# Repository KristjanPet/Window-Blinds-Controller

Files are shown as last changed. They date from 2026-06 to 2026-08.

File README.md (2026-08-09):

> [!NOTE]
> This is the first hardware version of the project. Both the PCB and mechanical design are relatively bulky; a second revision is in development with the goal of reducing the overall size by approximately 80%.
>
> Contributions, design ideas, and improvement suggestions are more than welcome.

# Window Blinds Controller

ESP32-S3 based embedded controller for motorized window blinds, built with C++/ESP-IDF, TMC2209 stepper control, FreeRTOS event-driven architecture, MQTT integration, custom KiCad PCB, and custom mechanical parts.

<p align="center">
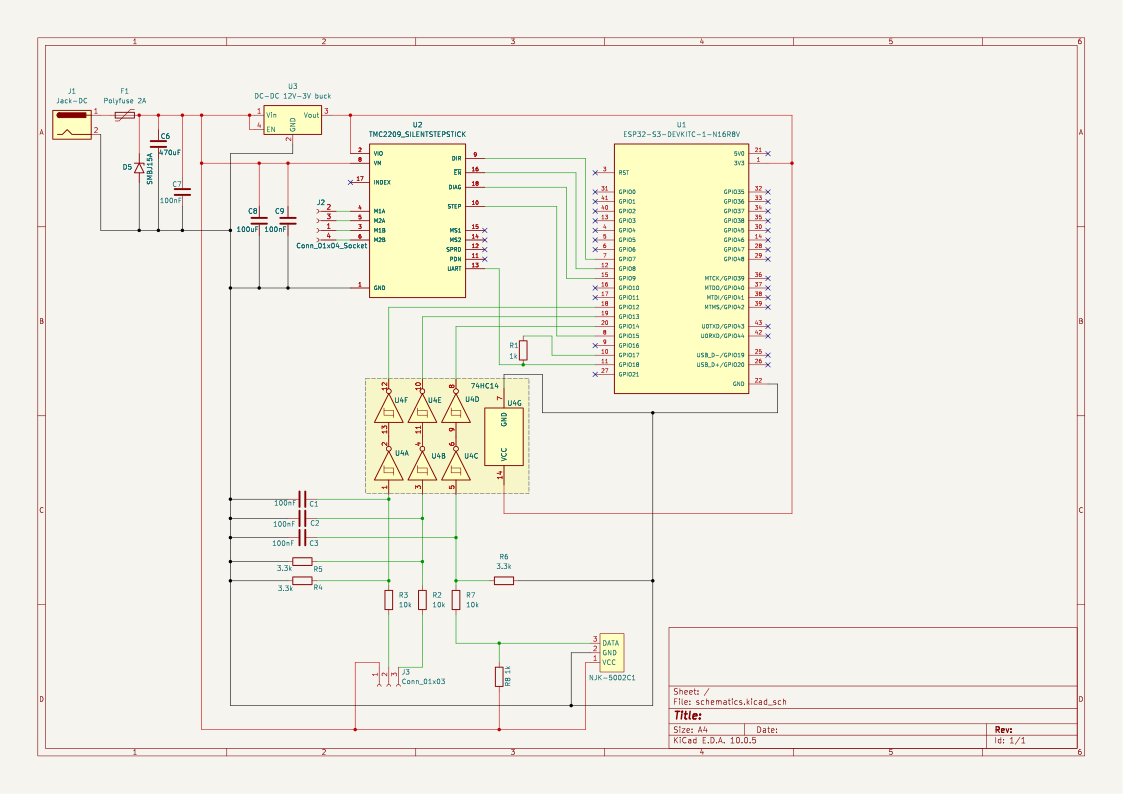
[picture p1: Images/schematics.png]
  
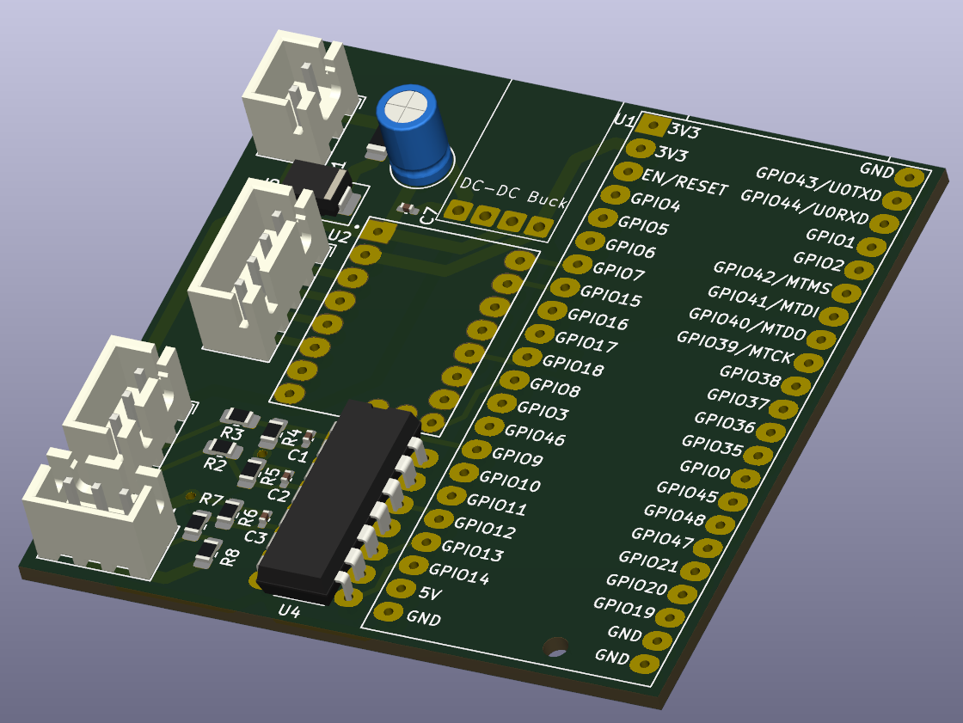
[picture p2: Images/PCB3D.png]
  
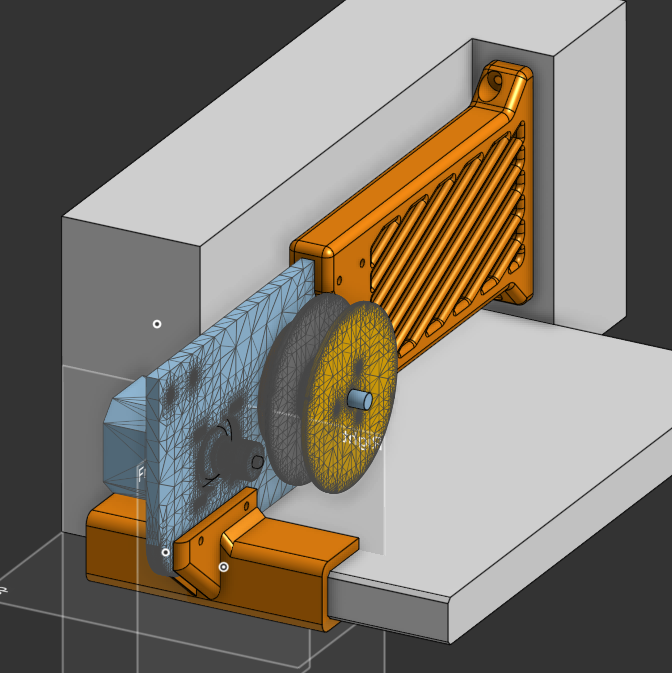
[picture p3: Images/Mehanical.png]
  
</p>
<p align="center">
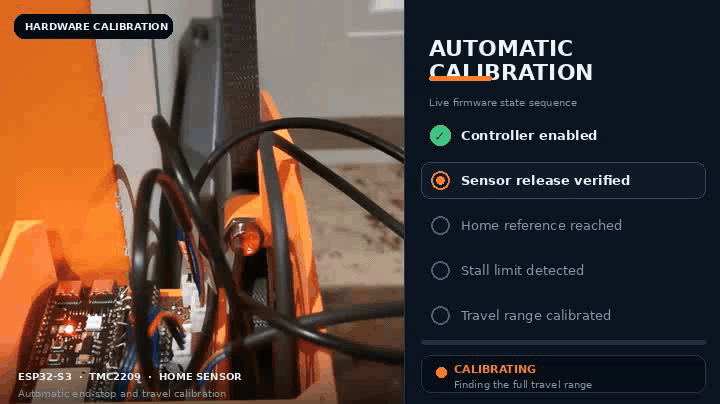
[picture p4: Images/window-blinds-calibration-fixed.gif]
ESP32-S3 window blinds automatic calibration with sensor verification, homing and stall detection
  
</p>

## What this project demonstrates

- Embedded C++ architecture using separated modules and interfaces
- ESP32-S3 firmware development with ESP-IDF and PlatformIO
- FreeRTOS task-based design with a central command/event queue
- Stepper motor control using RMT pulse generation and PCNT position tracking
- TMC2209 UART driver configuration and DIAG/stall event handling
- Homing, calibration, soft limits, stall recovery, and fault-state handling
- MQTT-based smart-home command interface
- Unit testing with PlatformIO/Unity and fake hardware abstractions
- Custom KiCad schematic and PCB design
- Custom mechanical design: CNC aluminium motor/rope holder and 3D printed enclosure
- Doxygen API documentation
- Project planning using Jira and draw.io diagrams

---

## Hardware

Main components:

| Component | Purpose |
|---|---|
| ESP32-S3 | Main MCU, Wi-Fi, FreeRTOS firmware |
| TMC2209 | Stepper motor driver with UART configuration and DIAG/stall signal |
| Nema 17 Stepper motor | Blind movement |
| NJK-5002C Home/reference sensor | Calibration and homing |
| Wall buttons | Local manual control |
| Custom PCB | Power, MCU, driver, sensor, and connector integration |

## Mechanical design

The project also includes custom mechanical parts:

- CNC aluminium motor and rope holder for the blind mechanism
- 3D printed front/back mounting holders for aluminium
- 3D printed electronics case
- 3D printed cover
- CAD models and exported STL/STEP files

## Documentation and planning

- Doxygen configuration for generated C++ API documentation
- draw.io diagrams for system architecture and firmware flow
- Jira used for task planning, issue tracking, and development organization

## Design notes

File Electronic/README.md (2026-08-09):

# Electronics Hardware

This folder contains the PCB and electronics design files for the window blinds controller.

The electronics are built around an ESP32-S3 development board, a TMC2209 stepper motor driver, a 12 V to 5 V buck converter, input protection, button/sensor connectors, and dual-inverter Schmitt-trigger input paths.

## Schematics



## Main electronics

| Component | Qty | Value / Part | Purpose |
| --- | --: | --- | --- |
| ESP32-S3 development board | 1 | `ESP32-S3-DEVKITC-1-N16R8V` | Main MCU, firmware, Wi-Fi, MQTT, GPIO control |
| Stepper driver | 1 | `TMC2209 SilentStepStick` | Stepper motor driver with UART configuration and DIAG/StallGuard output |
| Buck converter | 1 | 12 V to 3 V DC-DC buck | Generates 3 V supply from the 12 V input |
| Schmitt trigger | 1 | `74HC14` | Cleans three input signals with two inverter gates per signal |
| TVS diode | 1 | `SMBJ15A` | 12 V input transient protection |
| Polyfuse | 1 | 2 A | Input overcurrent protection |

## Passive components

| Component type | Qty | Value  |
| --- | --: | --- |
| Capacitors | 4 | 100 nF |
| Capacitor | 1 | 470 µF |
| Resistors | 2 | 1 kΩ |
| Resistors | 3 | 10 kΩ  |
| Resistors | 3 | 3.3 kΩ |

## Connectors

| Connector | Qty | Purpose |
| --- | --: | --- |
| 2-pin JST-XH | 1 | Power input |
| 4-pin JST-XH | 1 | External wiring / motor-driver related connection |
| 3-pin JST-XH | 1 | External input buttons connection |
| 3-pin JST-XH | 1 | NJK-5002C home sensor connection |

## Conditioned input logic

Each external input passes through two gates of the 74HC14. The two inversions
cancel, so the ESP32-S3 sees the same logical polarity as the signal entering the
first gate. The final gate is a 3.3 V push-pull output, so the firmware keeps the
ESP32 internal pull resistors disabled.

| Input | ESP32-S3 pin | Pre-Schmitt idle | Pre-Schmitt active | ESP32 idle | ESP32 active | Activation edge |
| --- | ---: | ---: | ---: | ---: | ---: | ---: |
| Up button | `GPIO12` | LOW | HIGH | LOW | HIGH | Rising |
| Down button | `GPIO13` | LOW | HIGH | LOW | HIGH | Rising |
| Home sensor | `GPIO14` | HIGH | LOW | HIGH | LOW | Falling |

## External hardware

The PCB is designed to work with the following external hardware:

| Part | Notes |
| --- | --- |
| 12 V, 3 A power supply adapter | Main power input for the controller and motor system |
| NEMA 17 stepper motor `17HS4401` | Stepper motor used to drive the blinds mechanism |
| GREATZT NJK-5002C Hall effect proximity sensor | Home/reference sensor for calibration |

Before choosing the motor and power supply, the weight and friction of the specific blinds should be checked. Heavier blinds, tight mechanisms, or higher-friction rope systems may require more torque, different gearing, or a stronger motor/driver setup.

## Design notes

The current PCB uses development-board style modules for the ESP32-S3, TMC2209 SilentStepStick, and DC-DC buck converter.

This made the prototype easier to build and debug because those modules were available during development. If space is critical, these modules could be replaced with direct SMD implementations in a future PCB revision.

Possible future optimizations:

* replace ESP32-S3 DevKit with the ESP32-S3 module (or any other not so overpowerd ESP) directly on the PCB
* replace TMC2209 SilentStepStick with the bare TMC2209 IC and required support components
* replace the buck converter module with an onboard SMD regulator circuit
* reduce connector size or move connectors based on the final enclosure
* optimize PCB shape for the mechanical case

<p align="center">
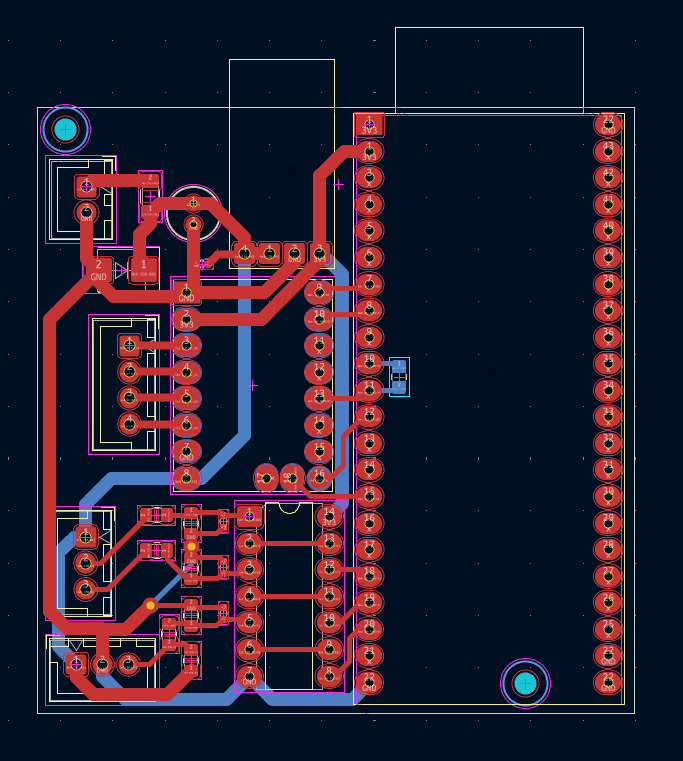
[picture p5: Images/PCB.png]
  
  
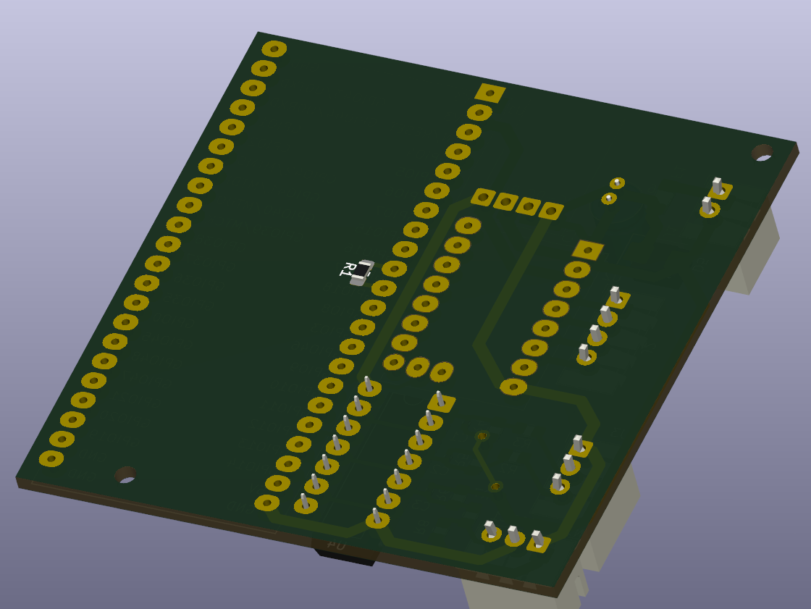
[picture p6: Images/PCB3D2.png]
  
</p>

## Safety note

This board controls a motorized mechanism. Before installation, verify:

* correct supply voltage and polarity
* current rating of the power adapter
* stepper motor current settings
* fuse/protection behavior
* connector wiring
* home sensor behavior
* motor direction
* stall detection
* mechanical end stops

Do not operate the blinds unattended until calibration, stall detection, and fault handling have been tested on the real mechanism.

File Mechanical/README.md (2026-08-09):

# Mechanical Hardware

This folder contains the mechanical design files for the window blinds controller.

The design includes CNC-machined aluminium parts, 3D printed holders, and a 3D printed electronics enclosure.

<p align="center">
  
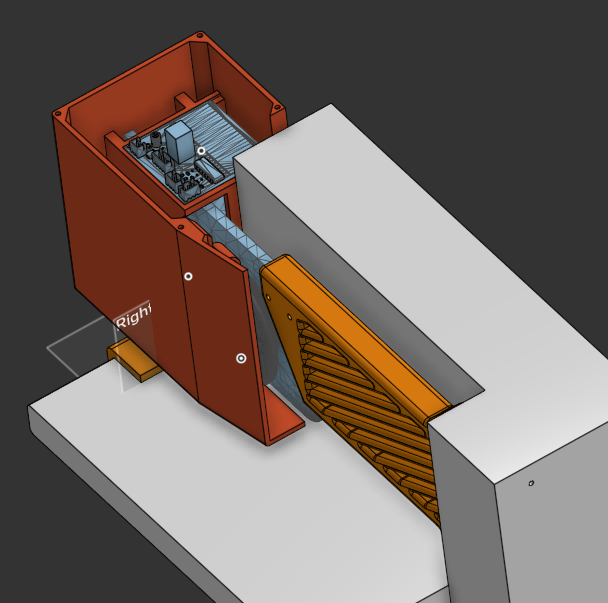
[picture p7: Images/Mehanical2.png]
  
</p>

## Main parts

| Part | Manufacturing method | Purpose |
| --- | --- | --- |
| Motor/rope holder | CNC aluminium | Holds the stepper motor and rope drive mechanism |
| Front holder | 3D printed or CAD reference | Supports the aluminium holder assembly |
| Back holder | 3D printed or CAD reference | Supports the aluminium holder assembly |
| Electronics case  | 3D printed | Holds the PCB, homing sensor, wiring, and sound absorbing foam |
| Cover | 3D printed | Removable cover for access and future upgrades |
| 1:8 pitch timing belt | bought online	  | increases available torque at the rope mechanism |

## Design notes

The aluminium motor/rope holder was CNC machined. The initial plan was to use only this aluminium part and mount it directly to the wall. Due to limited available space around the window and blinds, additional front/back holder parts were added around it.

The aluminium holder could also be 3D printed, or redesigned as a combined part together with the front and/or back holder, depending on the mounting constraints.

The overall mechanical design is probably overengineered and could be optimized. The best final shape depends strongly on the specific window frame, blind type, available mounting space, and required torque.

## Drive mechanism

A 1:8 pitch timing belt reduction is used between the stepper motor and the rope drive.

This increases available torque at the rope mechanism and gives the motor more control over blind movement.

## Fasteners

The assembly uses a few M4 bolts and screws. Exact lengths depend on the final printed/CNC part thickness and mounting surface.

## Electronics case

The electronics case is intentionally slightly larger than the minimum PCB size.

It includes space for:

* the main PCB
* homing sensor mounting
* PCB holders
* wiring clearance
* sound absorbing foam

The extra space was added to reduce noise and make the internal layout easier to service or modify.

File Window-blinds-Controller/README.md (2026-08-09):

# Firmware Project Structure

This folder contains the ESP32-S3 PlatformIO firmware project for the window blinds controller.

## Firmware architecture

The firmware is split into small C++ modules with clear responsibilities:

| Module | Responsibility |
|---|---|
| `BlindsController` | High-level state machine, calibration, movement policy, stall recovery |
| `MotorController` | STEP/DIR/EN control, RMT pulse generation, PCNT position tracking |
| `Tmc2209Driver` | UART register access, driver configuration, DIAG/stall event forwarding |
| `BlindsCommandQueue` | Central FreeRTOS command/event queue |
| `ButtonHandler` | Local wall-button input |
| `HomeSensor` | Reference sensor and homing validation |
| `MqttClient` | Remote commands and fault status publishing |
| `FaultHandler` | Thread-safe first-fault recording |

## Key engineering decisions

### RMT for step pulse generation
Stepper pulses are generated using the ESP32 RMT peripheral instead of software delay loops, reducing timing jitter and CPU load.

### PCNT for position tracking
The ESP32 PCNT peripheral is used to track generated step pulses and maintain position information.

### Event-driven control
Buttons, MQTT commands, motor events, home sensor events, and stall events are normalized into a central FreeRTOS command queue.

### Fault-first design
The system records the first fault and enters a safe fault state instead of silently ignoring failed operations.

### Testable architecture
High-level logic depends on interfaces/fakes where possible, allowing controller behavior and fault paths to be tested without real hardware.

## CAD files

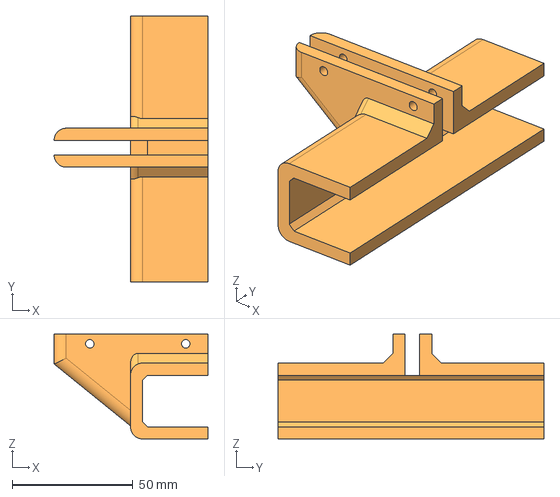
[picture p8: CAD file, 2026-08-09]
Mechanical/Back_Holder.step
63.6 x 110.0 x 43.4 mm

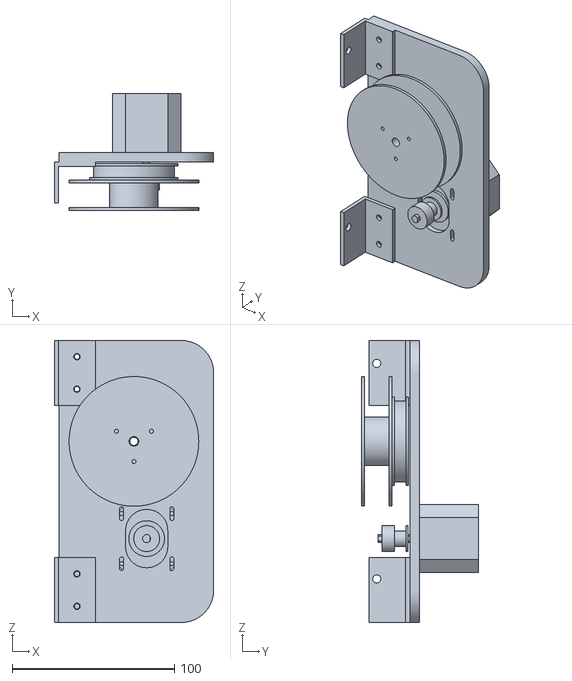
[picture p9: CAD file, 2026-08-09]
Mechanical/Aluminum_mechanism.stl
98.3 x 72.4 x 174.0

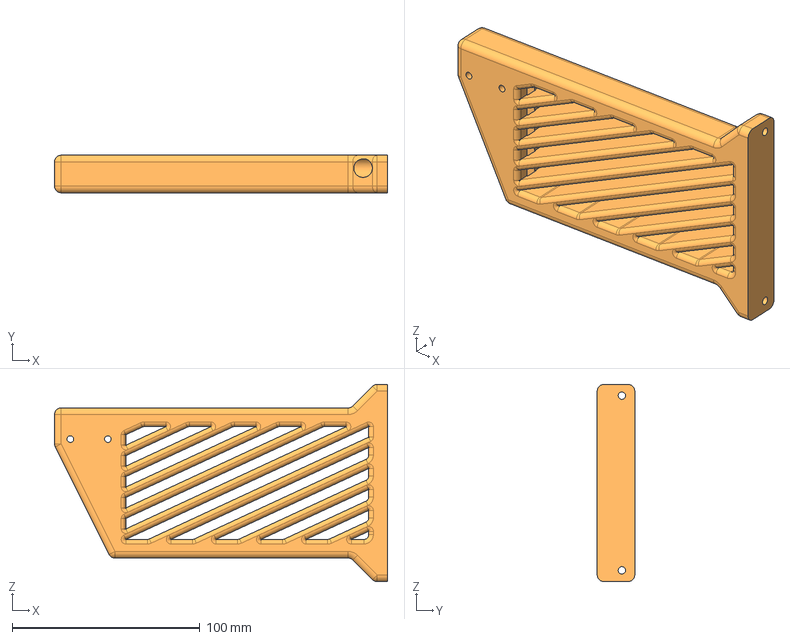
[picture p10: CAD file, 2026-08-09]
Mechanical/Front_Holder.step
177.3 x 20.0 x 105.0 mm

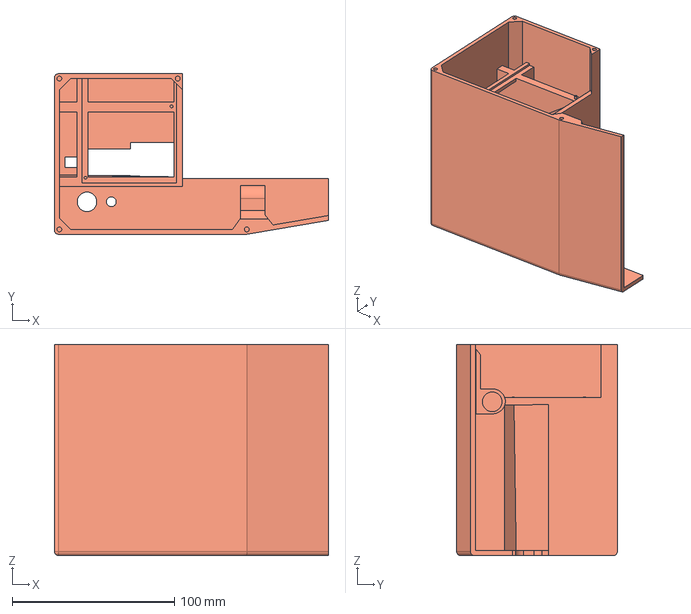
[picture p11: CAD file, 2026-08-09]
Mechanical/Case.step
168.6 x 98.8 x 130.0 mm

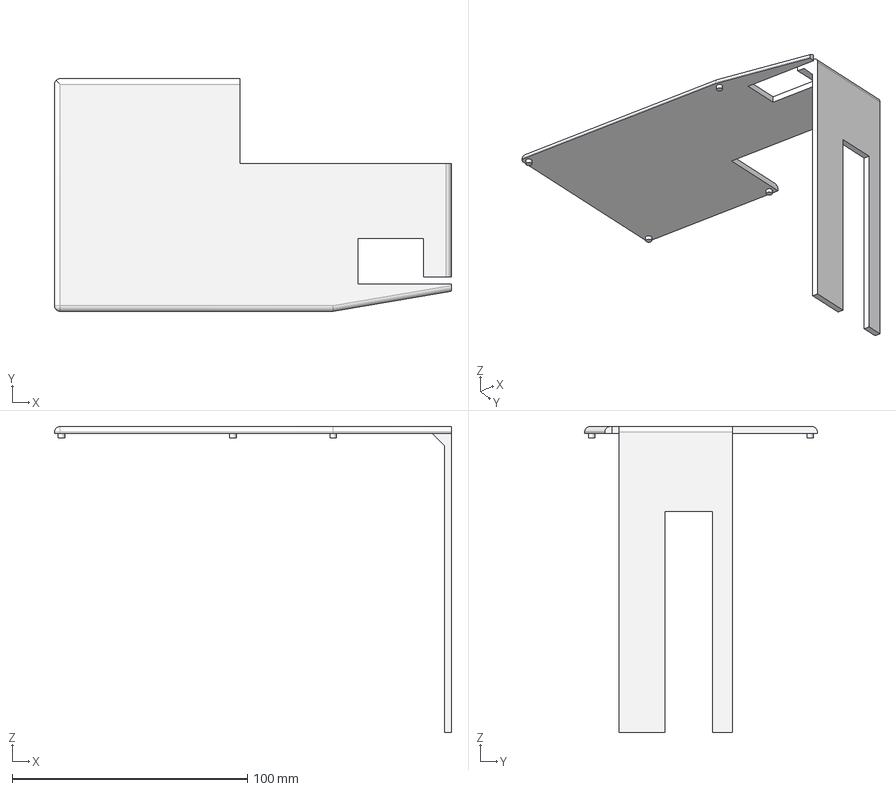
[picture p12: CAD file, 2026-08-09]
Mechanical/Cap.step
168.6 x 98.8 x 130.0 mm

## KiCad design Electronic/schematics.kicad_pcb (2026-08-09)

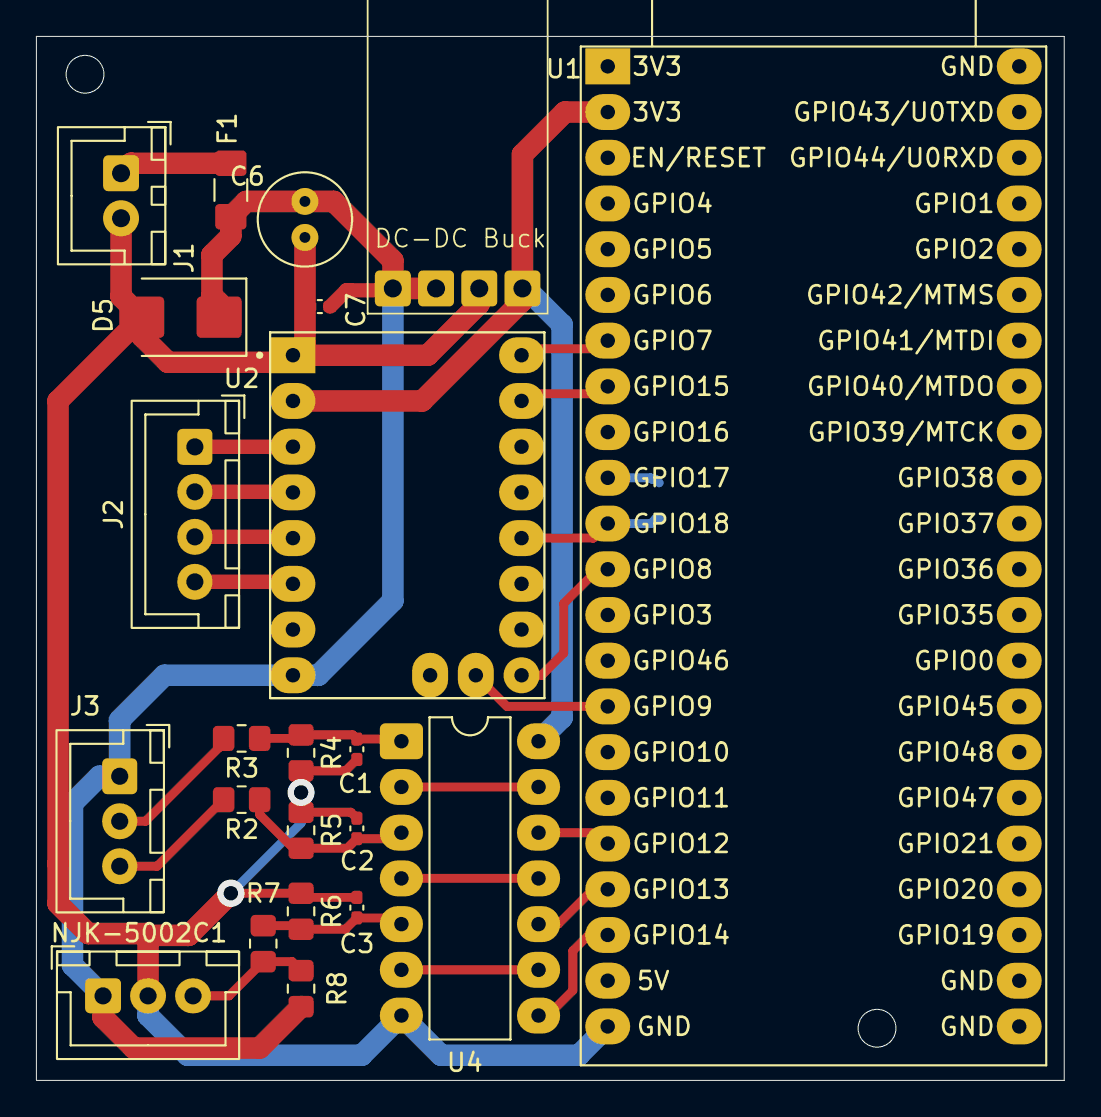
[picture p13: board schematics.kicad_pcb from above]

Board: 2 copper layers, 57.1 x 58.0 mm, 23 parts (1 on the bottom side), 26 nets.

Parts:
C1, C2, C3, C7: 100nF; C_0402_1005Metric_Pad0.74x0.62mm_HandSolder
C6: 470uF; C_Radial_D5.0mm_H7.0mm_P2.00mm
D5: SMBJ15A; D_SMB
F1: Polyfuse 2A; Fuse_1206_3216Metric_Pad1.42x1.75mm_HandSolder
J1: Jack-DC; JST_XH_B2B-XH-A_1x02_P2.50mm_Vertical
J2: Conn_01x04_Socket; JST_XH_B4B-XH-A_1x04_P2.50mm_Vertical
J3: Conn_01x03; JST_XH_B3B-XH-A_1x03_P2.50mm_Vertical
NJK-5002C1: JST_XH_B3B-XH-A_1x03_P2.50mm_Vertical
R1, R8: 1k; R_0805_2012Metric_Pad1.20x1.40mm_HandSolder
R2, R3, R7: 10k; R_0805_2012Metric_Pad1.20x1.40mm_HandSolder
R4, R5, R6: 3.3k; R_0805_2012Metric_Pad1.20x1.40mm_HandSolder
U1: ESP32-S3-DEVKITC-1-N16R8V; ESP32-S3-DevKitC
U2: TMC2209_SILENTSTEPSTICK; MODULE_TMC2209_SILENTSTEPSTICK
U3: DC-DC 12V-3V buck; DC-DC-Buck-converter-12V-5V
U4: 74HC14; DIP-14_W7.62mm_LongPads

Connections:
3V3: U1.1 (3V3), U2.2 (VIO), U3.3 (Vout), U4.14 (VCC)
GND: C1.1, C2.1, C3.1, C6.2, C7.2, D5.2 (A2), J1.2, NJK-5002C1.2 (GND), R4.2, R5.2, R6.2, U1.22 (GND), U2.1 (GND), U2.7 (GND), U3.2 (GND), U4.7 (GND)
unnamed: C1.2, R3.1, R4.1, U4.1
unnamed: C2.2, R2.1, R5.1, U4.3
unnamed: C3.2, R6.1, R7.2, U4.5
unnamed: J3.3, R2.2
unnamed: J3.2, R3.2
unnamed: NJK-5002C1.3 (DATA), R7.1, R8.2
unnamed: C6.1, C7.1, D5.1 (A1), F1.1, J3.1, NJK-5002C1.1 (VCC), R8.1, U2.8 (VM), U3.1 (Vin), U3.4 (EN)
unnamed: F1.2, J1.1
unnamed: J2.2 (Pin_1), U2.4 (M1A)
unnamed: J2.3 (Pin_2), U2.5 (M2A)
unnamed: J2.1 (Pin_3), U2.3 (M1B)
unnamed: J2.4, U2.6 (M2B)
unnamed: U1.7 (GPIO7), U2.9 (DIR)
unnamed: U1.12 (GPIO8), U2.16 (~EN)
unnamed: U1.15 (GPIO9), U2.18 (DIAG)
unnamed: U1.18 (GPIO12), U4.12
unnamed: U1.19 (GPIO13), U4.10
unnamed: U1.20 (GPIO14), U4.8
unnamed: U1.8 (GPIO15), U2.10 (STEP)
unnamed: R1.1, U1.10 (GPIO17)
unnamed: R1.2, U1.11 (GPIO18), U2.13 (UART)
unnamed: U4.6, U4.9
unnamed: U4.4, U4.11
unnamed: U4.2, U4.13

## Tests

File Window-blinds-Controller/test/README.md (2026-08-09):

## Testing

The firmware includes PlatformIO/Unity unit tests for:

- blinds state machine behavior
- button command handling
- stop and limit handling
- stall recovery logic
- calibration failure paths
- percentage-position movement
- MQTT command parsing
- JSON fault-status payload generation
- command queue and fault handling

Run tests:

```bash
pio test -e esp32-s3

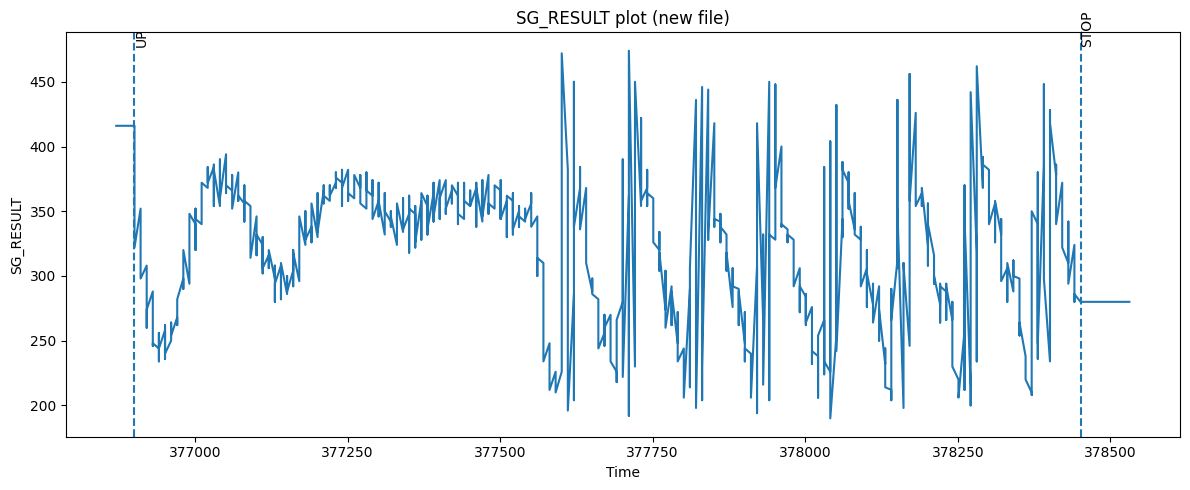
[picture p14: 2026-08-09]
Images/sg_result_close.png

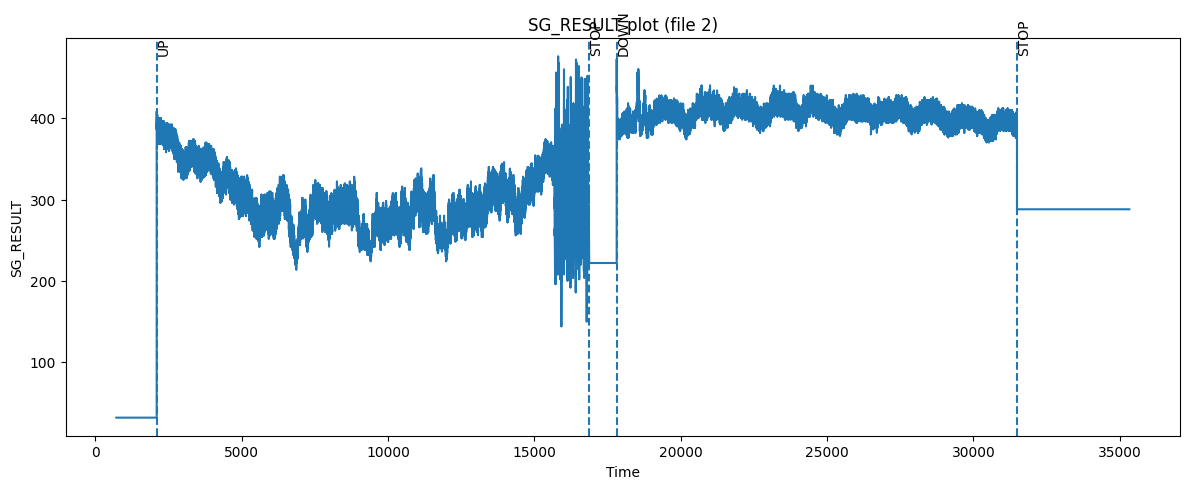
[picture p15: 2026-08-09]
Images/sg_result_all.png

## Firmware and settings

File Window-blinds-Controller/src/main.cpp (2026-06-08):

#include <esp_log.h>
#include <esp_system.h>
#include <driver/gpio.h>
#include <freertos/FreeRTOS.h>
#include <freertos/task.h>
#include "MotorController.hpp"
#include "ButtonHandler.hpp"
#include "HomeSensor.hpp"
#include "BlindsController.hpp"
#include "BlindsCommandQueue.hpp"
#include "Tmc2209Driver.hpp"
#include "AppConfig.hpp"
#include "FaultHandler.hpp"
#include "Wifi.hpp"
#include "MqttClient.hpp"
#include "ConnSecrets.hpp"

static const char *TAG_MAIN = "MAIN";

static FaultHandler faultHandler;
static BlindsCommandQueue commandsQueue(faultHandler);
static Tmc2209Driver motorDriver(AppConfig::UARTDriverPin, commandsQueue);
static MotorController motor(AppConfig::motorPins, commandsQueue, faultHandler);
static BlindsController blinds(motor, commandsQueue, faultHandler);
static ButtonHandler buttonHandler(AppConfig::buttonPins, commandsQueue);
static HomeSensor homeSensor(AppConfig::homeSensorPin, commandsQueue, faultHandler);
static Wifi wifi;
static MqttClient mqtt(commandsQueue, faultHandler);

extern "C" void app_main(void) {

    esp_err_t err = ESP_OK;
    err = commandsQueue.init();
    if(err != ESP_OK){
        ESP_LOGE(TAG_MAIN, "Command queue init failed: %s", esp_err_to_name(err));
        esp_restart();
    };

    err = gpio_install_isr_service(0);
    if(err != ESP_OK){
        ESP_LOGE(TAG_MAIN, "Failed to install GPIO ISR service: %s", esp_err_to_name(err));
        esp_restart();
    };

    err = motorDriver.init();
    if(err != ESP_OK){
        ESP_LOGE(TAG_MAIN, "TMC2209 init failed: %s", esp_err_to_name(err));
        esp_restart();
    };
    err = motorDriver.configureAndVerify();
    if(err != ESP_OK){
        ESP_LOGE(TAG_MAIN, "TMC2209 config failed: %s", esp_err_to_name(err));
        esp_restart();
    };

    err = motor.init();
    if(err != ESP_OK){
        ESP_LOGE(TAG_MAIN, "Motor init failed: %s", esp_err_to_name(err));
        esp_restart();
    };

    err = buttonHandler.init();
    if(err != ESP_OK){
        ESP_LOGE(TAG_MAIN, "Button handler init failed: %s", esp_err_to_name(err));
        esp_restart();
    };

    err = homeSensor.init();
    if(err != ESP_OK){
        ESP_LOGE(TAG_MAIN, "Home sensor init failed: %s", esp_err_to_name(err));
        esp_restart();
    };

    err = wifi.startAndConnect(ConnSecrets::wifiSsid, ConnSecrets::wifiPassword);
    if(err != ESP_OK){
        ESP_LOGW(TAG_MAIN, "WiFi start/connect failed, continuing without WiFi: %s", esp_err_to_name(err));
    }

    err = mqtt.init(ConnSecrets::mqttBrokerUri, ConnSecrets::mqttUsername, ConnSecrets::mqttPassword);
    if(err != ESP_OK){
        ESP_LOGW(TAG_MAIN, "MQTT init failed, continuing without MQTT: %s", esp_err_to_name(err));
    }
    else{
        err = mqtt.start(wifi.connectionEvents());
        if(err != ESP_OK){
            ESP_LOGW(TAG_MAIN, "MQTT start failed, continuing without MQTT: %s", esp_err_to_name(err));
        }
    }

    if(xTaskCreate(ButtonHandler::buttonTask, "Button", 2048, &buttonHandler, 3, NULL) != pdPASS){
        ESP_LOGE(TAG_MAIN, "Failed to create Button task, restarting...");
        esp_restart();
    }
    if(xTaskCreate(BlindsController::handleCommandTask, "Blinds", 4096, &blinds, 4, NULL) != pdPASS){
        ESP_LOGE(TAG_MAIN, "Failed to create handle command task, restarting...");
        esp_restart();
    }

    vTaskDelay(pdMS_TO_TICKS(500));
    ESP_LOGI(TAG_MAIN, "Init complete, checking sensor....");

    err = homeSensor.sensorCheck();
    if(err != ESP_OK){
        ESP_LOGE(TAG_MAIN, "Homing sensor check failed: %s", esp_err_to_name(err));
        esp_restart();
    };

    vTaskDelay(pdMS_TO_TICKS(1000));
    ESP_LOGI(TAG_MAIN, "calibrating blinds....");

    if(commandsQueue.send(BlindsEvent::CALIBRATE) != pdTRUE){
        ESP_LOGE(TAG_MAIN, "Failed to start calibrating, restarting...");
        esp_restart();
    }


    while (true){
        vTaskDelay(pdMS_TO_TICKS(100));
    }
    
}

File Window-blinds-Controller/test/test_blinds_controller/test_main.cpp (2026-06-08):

#include <unity.h>

void setUp(void) {}
void tearDown(void) {}

void test_motor_moving_up(void);
void test_motor_moving_down(void);
void test_same_button_toggle_up(void);
void test_same_button_toggle_down(void);
void test_toggle_style_up_down(void);
void test_toggle_style_down_up(void);
void test_normal_stop_while_moving_up(void);
void test_stop_failure_while_moving_up(void);
void test_limit_reached_stops_and_sets_idle(void);
void test_limit_reached_stop_failure_enters_fault(void);
void test_move_up_failure_from_idle(void);
void test_move_down_failure_from_idle(void);
void test_blinds_state_fault_up(void);
void test_blinds_state_fault_down(void);
void test_blinds_state_fault_stop(void);
void test_blinds_state_fault_limit_reached(void);

void test_up_stall_backs_off_and_enters_recovery(void);
void test_down_stall_backs_off_clamped_to_max_and_enters_recovery(void);
void test_stall_recovery_limit_reached_retries_original_up_target(void);
void test_stall_recovery_limit_reached_retries_original_down_target(void);
void test_stall_recovery_retry_stop_failure_enters_fault(void);
void test_three_stall_recoveries_are_allowed_then_fourth_stall_faults(void);
void test_target_reached_resets_stall_recovery_count(void);
void test_stop_resets_stall_recovery_count(void);
void test_stall_stop_failure_enters_fault(void);
void test_stall_recovery_move_failure_enters_fault(void);

void test_home_calibration_stall_recovers_and_continues_calibrating_home(void);
void test_max_calibration_stall_before_threshold_recovers_and_continues_calibrating_max(void);
void test_calibration_stall_fourth_recovery_enters_fault(void);
void test_calibrate_move_failure_enters_fault(void);
void test_homing_reached_move_to_max_failure_enters_fault(void);
void test_calibration_returns_to_step_computed_at_homing(void);
void test_calibration_return_target_clamps_to_calibrated_max(void);
void test_calibration_return_move_failure_enters_fault(void);
void test_up_during_home_calibration_stops_and_enters_fault(void);
void test_up_during_max_calibration_stops_and_enters_fault(void);
void test_down_during_home_calibration_stops_and_enters_fault(void);
void test_down_during_max_calibration_stops_and_enters_fault(void);

void test_percent_target_moves_up_with_rounding(void);
void test_percent_target_moves_down(void);
void test_percent_endpoint_targets_use_zero_and_max(void);
void test_percent_target_rejected_before_calibrated_max(void);
void test_percent_command_retargets_while_moving(void);
void test_percent_retarget_stop_failure_enters_fault(void);
void test_percent_during_calibration_stops_and_enters_fault(void);

extern "C" void app_main(void) {
    UNITY_BEGIN();

    RUN_TEST(test_motor_moving_up);
    RUN_TEST(test_motor_moving_down);
    RUN_TEST(test_same_button_toggle_up);
    RUN_TEST(test_same_button_toggle_down);
    RUN_TEST(test_toggle_style_up_down);
    RUN_TEST(test_toggle_style_down_up);
    RUN_TEST(test_normal_stop_while_moving_up);
    RUN_TEST(test_stop_failure_while_moving_up);
    RUN_TEST(test_limit_reached_stops_and_sets_idle);
    RUN_TEST(test_limit_reached_stop_failure_enters_fault);
    RUN_TEST(test_move_up_failure_from_idle);
    RUN_TEST(test_move_down_failure_from_idle);
    RUN_TEST(test_blinds_state_fault_up);
    RUN_TEST(test_blinds_state_fault_down);
    RUN_TEST(test_blinds_state_fault_stop);
    RUN_TEST(test_blinds_state_fault_limit_reached);

    RUN_TEST(test_up_stall_backs_off_and_enters_recovery);
    RUN_TEST(test_down_stall_backs_off_clamped_to_max_and_enters_recovery);
    RUN_TEST(test_stall_recovery_limit_reached_retries_original_up_target);
    RUN_TEST(test_stall_recovery_limit_reached_retries_original_down_target);
    RUN_TEST(test_stall_recovery_retry_stop_failure_enters_fault);
    RUN_TEST(test_three_stall_recoveries_are_allowed_then_fourth_stall_faults);
    RUN_TEST(test_target_reached_resets_stall_recovery_count);
    RUN_TEST(test_stop_resets_stall_recovery_count);
    RUN_TEST(test_stall_stop_failure_enters_fault);
    RUN_TEST(test_stall_recovery_move_failure_enters_fault);

    RUN_TEST(test_home_calibration_stall_recovers_and_continues_calibrating_home);
    RUN_TEST(test_max_calibration_stall_before_threshold_recovers_and_continues_calibrating_max);
    RUN_TEST(test_calibration_stall_fourth_recovery_enters_fault);
    RUN_TEST(test_calibrate_move_failure_enters_fault);
    RUN_TEST(test_homing_reached_move_to_max_failure_enters_fault);
    RUN_TEST(test_calibration_returns_to_step_computed_at_homing);
    RUN_TEST(test_calibration_return_target_clamps_to_calibrated_max);
    RUN_TEST(test_calibration_return_move_failure_enters_fault);
    RUN_TEST(test_up_during_home_calibration_stops_and_enters_fault);
    RUN_TEST(test_up_during_max_calibration_stops_and_enters_fault);
    RUN_TEST(test_down_during_home_calibration_stops_and_enters_fault);
    RUN_TEST(test_down_during_max_calibration_stops_and_enters_fault);

    RUN_TEST(test_percent_target_moves_up_with_rounding);
    RUN_TEST(test_percent_target_moves_down);
    RUN_TEST(test_percent_endpoint_targets_use_zero_and_max);
    RUN_TEST(test_percent_target_rejected_before_calibrated_max);
    RUN_TEST(test_percent_command_retargets_while_moving);
    RUN_TEST(test_percent_retarget_stop_failure_enters_fault);
    RUN_TEST(test_percent_during_calibration_stops_and_enters_fault);

    UNITY_END();
}

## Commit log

2026-03-13 Add hardware wiring scheme to README
    Added hardware wiring scheme section with schematics image.
    Starting with TMC2209 stepper motor driver and wall switches.
2026-03-14 Added images and schematics
    Added images for easier schematics update.
    Updated resistor divider at wall switches
2026-03-14 Update schematics image path in README.md
2026-03-15 Update schematics.png
    Added RC fillter and schmitt trigger to reduse noise
2026-03-16 Update schematics.png
    Added NJK-5002C1 proximity sensor
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2026-03-17 Setup controll buttons GPIO
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2026-03-18 Update button controll by using timer
2026-03-18 Updated button handeling by using queue and seperet task
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2026-03-19 Updated schematics - add bulk cap at motor driver
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2026-03-22 Moved motor pins & gptimer init to motor class
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2026-03-24 Fix motor moving logic
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2026-03-26 Updated ButtonHandler to use blinds class - updated buttonTask button logic
2026-03-26 Added logging error in case of false sendCommand
2026-03-27 Updated BlindsController sendComand - renamed to handleCommand - motorController get by reference insted of pointer - If state is Fault it stays fault - in case of fault state we get invalid state er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
    [main.cpp]
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2026-03-28 Added motor failure test
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2026-03-29 Added soft limit temporary replacing sensors - stepTimer counts steps and notify task - Task stops the gptimer on limit
2026-03-29 Added new switch case and change handleCommand method to task
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2026-03-30 Added commands queue in MotorController - for informing on limit reached
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2026-04-02 Added critical section to shared states in MotorController
2026-04-02 Main and Button error handleing improved
    [main.cpp]
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2026-04-21 Set motor current level on hold, run and delay
2026-04-21 Refactor Tmc2209Driver to use constants for UART configuration and improve error handling
    [main.cpp]
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2026-04-22 Updated Tmc2209Driver with DIAG pin handling and ISR integration; update configuration parameters for stall guard and UART driver pins
    [main.cpp]
2026-04-28 Add HomeSensor class and integrate home sensor functionality
2026-04-29 Implement homing detection and logging in BlindsController + added schmitt trigger
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2026-05-01 Enhance BlindsController to manage HOME state and update motor control logic
2026-05-02 Refactor motor control methods in MotorController to use a unified move function and update step handling logic
2026-05-02 Add POC calibration handling to BlindsController and initiate calibration in main
2026-05-07 Refactor BlindsController and MotorController for improved calibration handling and state management
2026-05-08 On limit ignore button press bug fix
2026-05-08 Refactor BlindsController and HomeSensor for sensor check at init POC
2026-05-09 Homing sensor check bugfix
2026-05-09 Enhance motor control with current step retrieval and improve stall detection logic
2026-05-11 Improve error handling in app_main
    [main.cpp]
2026-05-11 Add timer management in MotorController to improve stop functionality
2026-05-11 Refactor FakeMotor to improve state management and add calibration failure tests
    [FakeMotor.hpp]
2026-05-11 Update BlindsController to set state to FAULT on command handling errors and adjust test case naming for clarity
2026-05-12 Add moveToMax method to IMotor and update BlindsController to use it for motor movements
2026-05-13 Update handleCommand to set state to FAULT during calibration errors
2026-05-13 Add tests for fault state during calibration events in BlindsController
2026-05-14 Implement normal stall recovery in BlindsController
2026-05-14 Add tests for stall recovery scenarios in BlindsController
    [FakeMotor.hpp]
2026-05-14 Update stall recovery test to verify target step and move call counts
2026-05-14 Add stall recovery handling while calibrating
2026-05-14 Add tests for home calibration stall recovery scenarios
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2026-05-16 Add tests for calibration return handling and fault scenarios
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2026-05-18 Fix button handler configuration and logic for Schmitt trigger
2026-05-20 Refactor MotorController to implement RMT and PCNT functionality, removing timer-based logic
2026-05-20 Refactor MotorController to improve RMT transaction handling and position calculation
2026-06-03 Update schematics image - moved diodes - removed unnecessary capacitors
2026-06-04 Add unit tests for FaultHandler, MotorController, and MqttClient
    - Implemented tests for FaultHandler to verify fault recording and notification behavior.
    - Removed outdated test cases from test_motor_controller.cpp and created a new test file for MotorController.
    - Added tests for MotorController to ensure it rejects invalid movement targets.
    - Created a new test file for MqttClient, including tests for MQTT payload parsing and fault status payload generation.
2026-06-05 Switched from ESP32-U to S3 becouse of internal wifi antena and refactor GPIO pins
2026-06-07 Update schematics image to reflect recent design changes
2026-06-08 Update schematics image - Wrong wiring on R6
2026-06-09 Update build and test commands in AGENTS.md for ESP32-S3 environment
2026-06-11 Update schematics image - increase capacitor at power input - added 100uF & 100nF capacitor at TMC driver
2026-06-12 Refactor MotorController documentation and add missing method descriptions
2026-06-15 Enhance documentation for BlindsCommandQueue, BlindsController and ButtonHandler with detailed method descriptions and usage notes
2026-07-08 Add README for TMC2209 Driver module
    Added detailed documentation for TMC2209 driver, including purpose, pin usage, UART configuration, register addresses, StallGuard tuning, event handling, and verification process.
2026-07-09 Update README with stepper motor info and images
    Added references to the stepper motor model and updated the image display for StallGuard tuning plots.
2026-07-09 Add detailed documentation for BlindsController, HomeSensor, MotorController, and MQTT communication
2026-07-10 Add detailed mechanical hardware documentation including design notes, main parts, and assembly instructions
2026-07-12 Added KiCad files for schematics and pcb
    [schematics.kicad_pcb, schematics.kicad_sch]
2026-07-12 Added step files for 3D printed parts & STL file for CNC
    [Aluminum_mechanism.stl, Back_Holder.step, Cap.step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]
2026-07-13 Add PCB and 3D PCB images for documentation
2026-07-30 Changed logical polarity to follow schematics and improve documentation for button and home sensor handling
2026-08-04 Fix pull-down configuration in ButtonHandler and update PlatformIO settings for consistency
2026-08-06 Refactor schematics and update PCB images
    - Removed unconnected items from the KiCad project file.
    - Removed a diode symbol (PESD3V3S1UL) and its associated properties from the schematic.
    - Renamed and repositioned several pins in the TMC2209_SILENTSTEPSTICK symbol for clarity.
    - Cleaned up unnecessary junctions and wires in the schematic.
    - Updated multiple PCB and schematic images to reflect recent design changes.
    [schematics.kicad_pcb, schematics.kicad_sch]
2026-08-07 Added mechanical case and cap plus images and gif for demonstration
    [Cap.step, Case.step]
2026-08-09 Update README with additional images and calibration GIF
    Added images for schematics, 3D PCB, and mechanical parts, along with a calibration GIF.
2026-08-09 Update README with schematics and safety note
    Added schematics section and images to README.
